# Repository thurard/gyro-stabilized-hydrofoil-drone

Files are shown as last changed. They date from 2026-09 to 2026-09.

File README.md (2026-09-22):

# 🌊 Gyro-Stabilized Hydrofoil Drone

A remote-controlled **hydrofoil drone** (a foiling boat) kept level by a
**gyroscopic stabilization system**. This SeaTech engineering project spans the whole
chain — functional analysis, **MATLAB/Simulink (Simscape) modelling**, CAD, 3D printing,
electronics and a **working prototype tested on the water**.

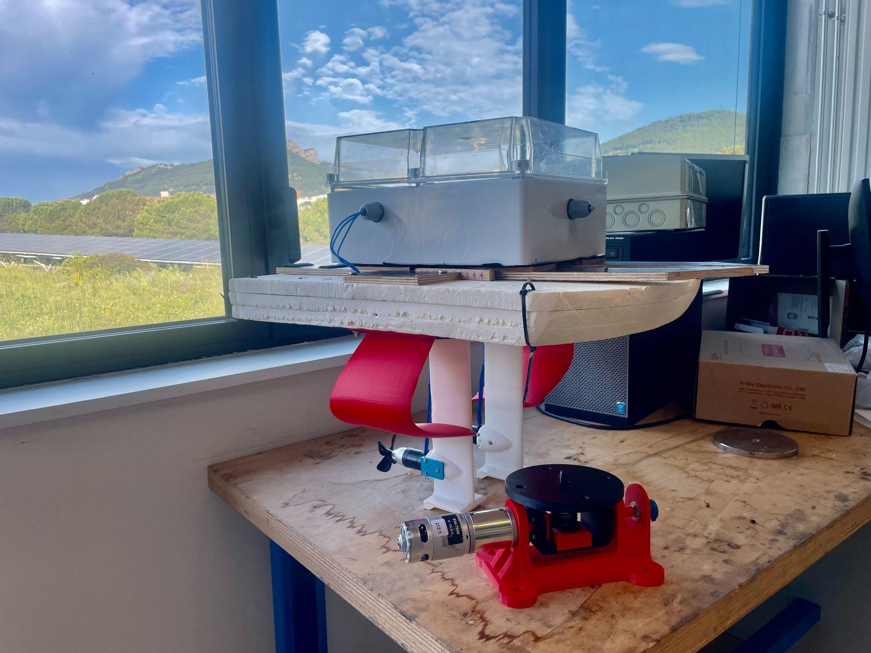
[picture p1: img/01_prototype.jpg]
Prototype


> The gyroscope in action: as the mount is tilted by hand, the spinning flywheel resists
> and holds its orientation — the same effect that keeps the foil platform level.

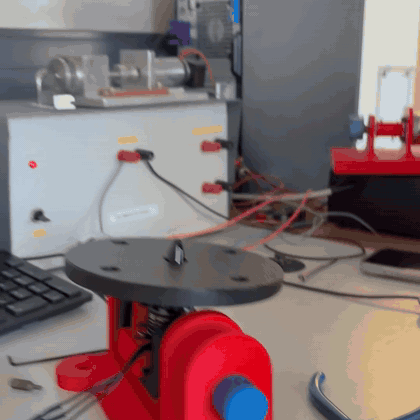
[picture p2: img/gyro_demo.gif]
Gyroscope in action


---

## Contents

- [Overview](#overview)
- [How it works](#how-it-works)
- [Simulation — the focus of this repo](#simulation--the-focus-of-this-repo)
- [Design & prototype](#design--prototype)
- [Repository structure](#repository-structure)
- [Running the simulation](#running-the-simulation)
- [Report](#-report)
- [Authors & contributions](#authors--contributions)

---

## Overview

Project of the **SYSMER** track (marine & robotic systems) at SeaTech — University of
Toulon, 2025–2026. A team of five designed and built a small remote-controlled hydrofoil
craft whose deck stays level thanks to a gyroscope.

The system combines **two complementary subsystems**:

1. **Gyroscopic stabilization** — *mechanical & passive*. A motor spins a flywheel; by
   conservation of angular momentum it resists roll and pitch and keeps the foil platform
   flat, without any active control loop.
2. **Embedded flight control** — *electronic & active*. Handles piloting, propulsion and
   the foiling height (how high the hull rides above the water).

---

## How it works

**Gyroscopic stabilization (passive).** The flywheel's angular momentum opposes any
tilt of the platform. The key design question is *where to place the centre of gravity*
so the stabilization is effective in both roll and pitch — this is exactly what the
Simulink model answers (see below).

**Embedded flight control (active).** The signal chain:

```
FlySky X7 radio → receiver → flight controller (Pixhawk / Navigator, running BlueOS)
→ Lua scripts ("motors", "height") read the height sensor and drive the motors
→ regulating the foiling height and the propulsion.
```

BlueOS is Blue Robotics' onboard operating system; the custom **Lua scripts** run on the
flight controller to close the height-regulation and propulsion loops.

---

## Simulation — the focus of this repo

The gyroscopic stabilization was modelled in **MATLAB / Simulink (Simscape Multibody)**.
The goal: find the **optimal longitudinal position of the centre of gravity** so that,
under a disturbance, the platform returns to level (0° = perfectly flat).

- `init_naca.m` — generates the **NACA 0012** foil (chord 0.15 m) and its winglet, and
  loads their coordinates into the workspace for the Simscape wing blocks.
- `Gyro_tanga.slx` + `Gyro_Tanga.m` — **pitch** study: sweeps 8 CoG positions
  (−0.25 m → −0.05 m) and plots the resulting pitch angle over time.
- `Gyro_roulis.slx` + `Gyro_Roulis.m` — **roll** study: sweeps CoG positions
  (−0.15 m → +0.15 m) and plots the roll angle.

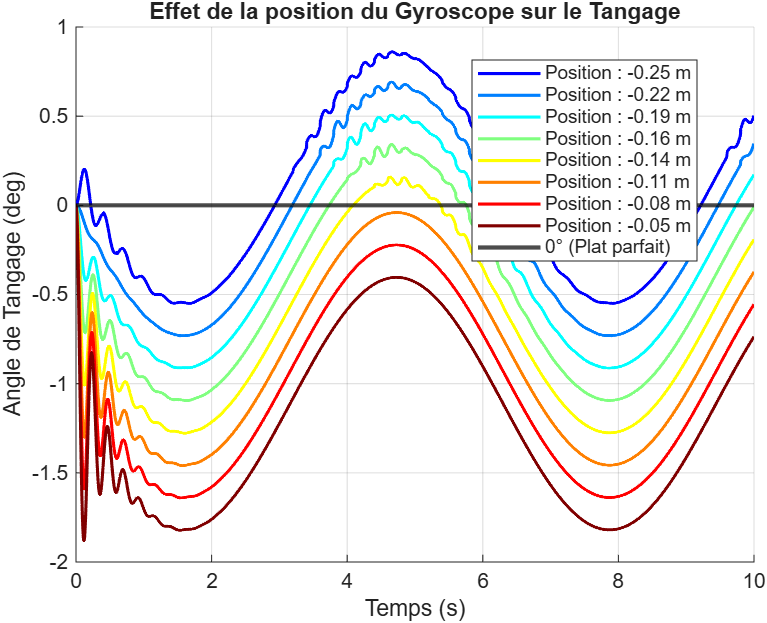
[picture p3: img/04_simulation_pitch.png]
Pitch sweep


*Effect of the CoG longitudinal position on pitch: the curve closest to 0° identifies
the best CoG placement for a stable, level platform.*

---

## Design & prototype

| | |
|---|---|
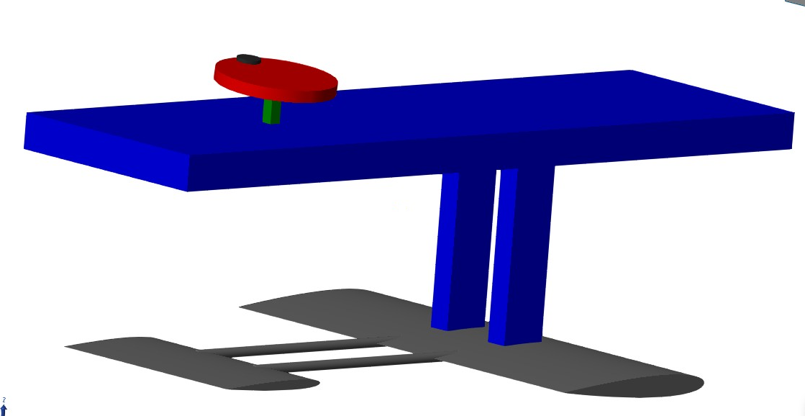
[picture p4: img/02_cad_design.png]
CAD
|  | **CAD** of the full foiling drone (deck + foils + gyroscope). |
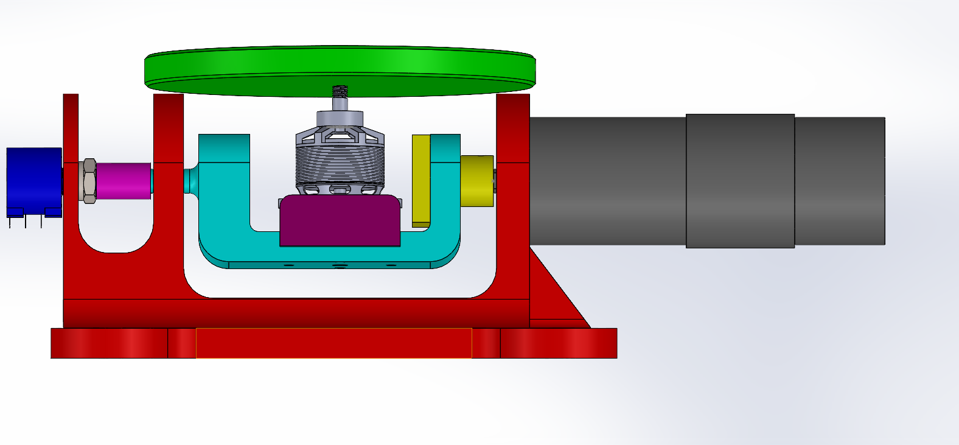
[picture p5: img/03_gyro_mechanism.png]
Gyro mechanism
|  | Cutaway of the **gyroscope mechanism** (motor + flywheel + gimbal). |
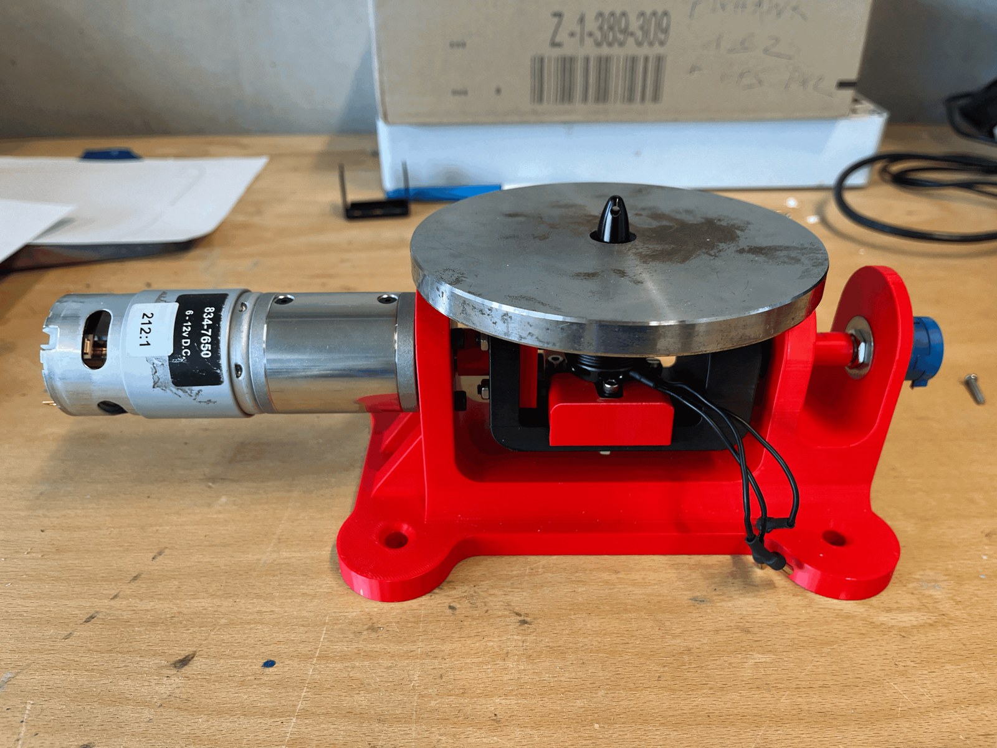
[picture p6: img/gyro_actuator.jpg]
Gyroscope prototype
|  | The **3D-printed gyroscope** assembled (mount + motor + flywheel). |
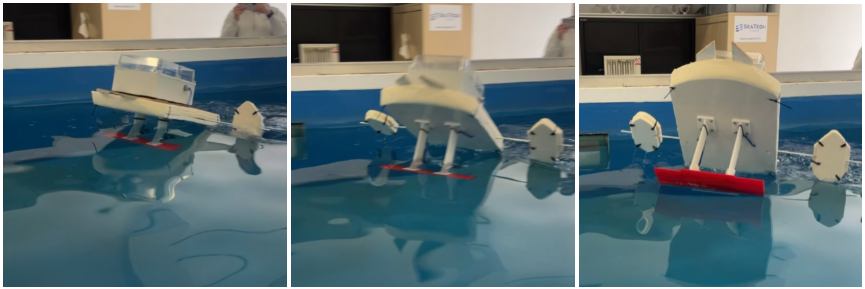
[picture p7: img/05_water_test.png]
Water test
|  | **On-water tests** of the prototype. |

The mechanical parts were **3D-printed**, assembled with the motors, flywheel, foils and
electronics, and tested on the water.

---

## Repository structure

```
.
├── init_naca.m             % NACA 0012 foil + winglet generation
├── Gyro_tanga.slx          % Simscape model — pitch
├── Gyro_Tanga.m            % CoG sweep (pitch) + plot
├── Gyro_roulis.slx         % Simscape model — roll
├── Gyro_Roulis.m           % CoG sweep (roll) + plot
├── Rapport.pdf             % Full project report (French)
├── presentation.pptx       % Project presentation (optional)
├── img/                    % Renders, prototype photos, results
└── README.md
```

---

## Running the simulation

**Requirements:** MATLAB with **Simulink** and **Simscape Multibody**.

```matlab
% From the repository folder, simply run a sweep script — it loads the NACA
% profiles and the Simulink model automatically:
Gyro_Tanga     % pitch study (sweeps the CoG, plots the pitch response)
Gyro_Roulis    % roll study
```

Each script opens its Simscape model, runs the simulation for 8 centre-of-gravity
positions, and overlays the angle responses so the best placement stands out.

---

## 📄 Report

Full project report — functional analysis, gyroscopic system, Simulink study, 3D design,
embedded system and prototype results (in French):

**➡️ [Rapport.pdf](Rapport.pdf)**

---

## Authors & contributions

Five-person project — SeaTech (University of Toulon), SYSMER, 2025–2026. Supervised by
Cédric Anthierens.

| Subsystem | Members |
|---|---|
| **Gyroscopic stabilization** (mechanical design, Simulink/Simscape modelling, CoG optimization, foil) | **Tom Hurard**, **Amélie Duchemin** |
| **Embedded flight control** (BlueOS, Lua scripting, RC piloting, height sensor, propulsion) | **Marie Bernard-Lameau**, **Anatole Collange**, **Antoine Hureau** |

*This repository centres on the gyroscopic-stabilization simulation. The embedded flight
control was developed by the other three team members and is described here for context.*

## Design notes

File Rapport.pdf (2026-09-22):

# Rapport de Projet

Réalisation d’un drone à foil télécommandé avec stabilisation gyroscopique

Encadrant :

ANTHIERENS Cédric

Étudiants :

BERNARD-LAMEAU Marie
COLLANGE Anatole
DUCHEMIN Amélie
HURARD Tom
HUREAU Antoine

SYSMER 2A

Année universitaire 2025–2026

## Table des matières

Remerciements | 3
Résumé | 4
1 Introduction | 6
2 Analyse du projet | 7
3 Système de stabilisation gyroscopique | 11

### 3.3.2 Limitation à un unique gyroscope et réorientation de l’étude . . . . 12

4 Système embarqué | 18
5 Maquette | 23

1

6 Axes d’évolution et d’amélioration du projet | 30
7 Conclusion | 32
A Coder en Lua | 33
B Tutoriel BlueOS | 37
C Scripts MATLAB | 41
D Mises en plan | 44
E Protocole d’assemblage | 51

2

## Remerciements

Nous tenons à remercier chaleureusement toutes les personnes ayant collaboré, de près ou de loin, à la réalisation de ce projet.
Tout d’abord, nous tenons à remercier M. ANTHIERENS, notre enseignant référent, de nous avoir encadrés et conseillés tout au long de notre projet, tant sur la méthodologie de travail que sur la résolution des différentes problématiques techniques rencontrées. Nous tenons aussi à remercier M. DEGORRE, pour sa réactivité et son aide précieuse concernant les montages électriques, l’utilisation de Blue OS et la conception de pièces tout au long de ce projet.
Nous remercions également les étudiants des années précédentes — Amélie VOGEL, Matthis BARRIOL, Chloé BERTRAND-ADAM, Anthony GRAILLE et Arthur VARRE, — de nous avoir guidés et d’avoir partagé leurs travaux avec nous, nous permettant ainsi de reprendre ce projet dans les meilleures conditions.

3

## Résumé

Ce projet s’inscrit dans la continuité des travaux menés par d’anciens élèves en partenariat avec l’entreprise ZYX Blue, portant sur la conception d’un drone de surface à foil télécommandé équipé d’un système de stabilisation gyroscopique. Ainsi, l’objectif est de permettre au drone de décoller sur ses foils et de maintenir son altitude, grâce à une combinaison de solutions mécaniques, hydrodynamiques et électroniques.

Un nouveau foil autostabilisant a été conçu sous SolidWorks pour pallier l’instabilité du foil en T. Le système gyroscopique a été entièrement repensé avec une architecture en U plus rigide et compacte, validée par prototypage rapide. Le système embarqué repose sur une Raspberry Pi 5 couplée à une carte Navigator, fonctionnant sous BlueOS, et commandé via une télécommande Taranis QX7 à 8 canaux. Des scripts Lua ont été développés pour la commande différentielle des moteurs de propulsion et la gestion du gyroscope. Un capteur à ultrasons a été intégré pour l’estimation de la hauteur de vol, même si la lecture des données avec la carte Navigator reste à finir. Des essais en bassin ont validé la flottabilité de la maquette (environ 10 L pour une masse totale de 4,1 kg) et permis d’obtenir des décollages répétables, même si la stabilisation automatique en altitude n’est pas encore opérationnelle.

Mots-clés

Drone foil, Stabilisation gyroscopique, BlueOS, ArduPilot, Lua, Raspberry Pi, Télécommande RC, Foil autostabilisant

4

Summary

This project builds on work previously carried out by former students in partnership with the company ZYX Blue, focusing on the design of a remote-controlled surface foil drone equipped with a gyroscopic stabilisation system. The aim is to enable the drone to take off on its foils and maintain its altitude, using a combination of mechanical, hydrodynamic and electronic solutions.

A new self-stabilising foil has been designed in SolidWorks to address the instability of the T-shaped foil. The gyroscopic system has been completely redesigned with a more rigid and compact U-shaped architecture, validated through rapid prototyping. The onboard system is based on a Raspberry Pi 5 coupled with a Navigator board, running on BlueOS, and controlled via an 8-channel Taranis QX7 remote control. Lua scripts have been developed for the differential control of the propulsion motors and the management of the gyroscope. An ultrasonic sensor has been integrated to estimate flight altitude, although data reading with the Navigator board still needs to be finalised. Tank tests have validated the model’s buoyancy (approximately 10 L for a total mass of 4.1 kg) and enabled repeatable take-offs, even though automatic altitude stabilisation is not yet operational.

Key words

Foiling drone, Gyroscopic stabilization, BlueOS, ArduPilot, Lua, Raspberry Pi, RC remote control, Self-stabilising foil

5

## 1 Introduction

Le développement d’un drone foileur performant représente un enjeu majeur pour la robotique marine moderne. Les foils permettent d’atteindre des vitesses élevées tout en réduisant la traînée, mais ils introduisent en contrepartie une forte sensibilité aux perturbations et aux variations d’assiette. La stabilité devient alors un facteur critique : sans un contrôle précis et réactif, le drone perd en efficacité, en sécurité et en capacité opérationnelle. C’est précisément pour répondre à cette problématique que ce projet s’inscrit dans la continuité des travaux menés au COSMER et avec l’entreprise ZYX Blue sur l’équilibrage dynamique par effet gyroscopique.
Ce projet reprend les travaux entrepris lors de précédents projets 2A et 3A SYSMER. Les promotions précédentes ont posé des bases importantes : une première architecture gyroscopique, un foil en T fonctionnel, et une maquette. Mais le travail n’était pas fini. Aucune implémentation n’avait été réalisée sous BlueOS, l’électronique était à revoir, le foil en T présente une tendance au phénomène de décrochage difficile à maîtriser et le gyroscope n’avait jamais été activé en conditions réelles.
Notre travail s’est donc organisé autour de trois axes principaux. D’abord, mettre en place l’ensemble du système embarqué sous BlueOS (commande moteur, télécommande, capteur de hauteur). Ensuite, repenser l’architecture mécanique du gyroscope pour la rendre plus compacte. Enfin, concevoir un nouveau foil à géométrie autoadaptative pour répondre au problème de décrochage constaté en bassin.

6

## 2 Analyse du projet

### 2.1 Cahier des charges et attendus du projet

Le projet consiste à concevoir un drone de surface à foils télécommandé, doté d’un système de stabilisation gyroscopique. Pour ce faire, nous avons réalisé les tâches suivantes :
— Intégration d’une télécommande et de son récepteur pour piloter les moteurs de propulsion par liaison radio,
— Réalisation de tests en bassin pour valider la flottabilité, l’étanchéité, et l’efficacité des foils,
— Dimensionnement et conception du système de stabilisation gyroscopique,
— Intégration d’un capteur de distance à ultrasons pour connaître la hauteur de vol pour garantir la stabilité du drone,
— Commande des gyroscopes, si l’intégration matérielle et logicielle le permet.
Une maquette composée d’un flotteur en mousse et d’un foil en T a déjà été réalisée par les groupes précédents.
Pour réaliser le système embarqué, nous disposons de :
— une boîte de dérivation étanche et des presse-étoupe,
— 1 Raspberry Pi couplée à une carte Navigator,
— 4 ESC, dont 3 brushless,
— 2 batteries,
— 1 télécommande et le récepteur associé,
— 1 buck converter,
— 4 moteurs : 2 pour la propulsion, 2 pour piloter le gyroscope. Pour réaliser le système gyroscopique, nous disposons de :
— 1 moteur brushless outrunner (600KV T-HOBBY)
— 1 motoreducteur à courant continu (834-7650 RS PRO)
— 1 potentiomètre 10 tours (2780303 RS PRO)
— 1 disque en métal de 1 kg

### 2.2 Analyse fonctionnelle

L’analyse fonctionnelle du drone vise à formaliser les interactions entre le système et son environnement extérieur, ainsi qu’à traduire les besoins exprimés en fonctions techniques. Cette étape préalable a guidé les choix d’architecture, en particulier pour la stabilisation gyroscopique, la propulsion, l’étanchéité et l’interface de pilotage.

7

### 2.2.1 Interacteurs

Il existe quatre entités extérieures en interaction avec le système. L’utilisateur pilote le drone, reçoit des informations sur sa position par rapport aux obstacles, et assure le transport ainsi que la mise à l’eau. La charge à déplacer sur l’eau constitue la prestation principale attendue du drone. L’environnement regroupe l’eau, le vent, les obstacles immergés ou en surface, ainsi que les agents de corrosion. Enfin, les ondes radio et l’alimentation électrique embarquée sont des interacteurs nécessaires au fonctionnement.

### 2.2.2 Fonctions de service

Deux fonctions de service (FP) ont été identifiées. La première (FP1) consiste à permettre à l’utilisateur de déplacer une charge sur l’eau. Les critères d’appréciation sont la vitesse de déplacement (au moins 2 nœuds), la capacité de charge utile (supérieure à 0,5 kg) et la stabilité de l’assiette en vol sur foils (maintien à ±10°). La seconde fonction (FP2) est d’informer l’utilisateur en temps réel de la position du drone par rapport aux obstacles environnants. Elle est assurée par un capteur à ultrasons qui mesure la hauteur de vol ou la distance aux obstacles, avec une portée minimale de 2 m et une fréquence de mise à jour d’au moins 10 Hz.

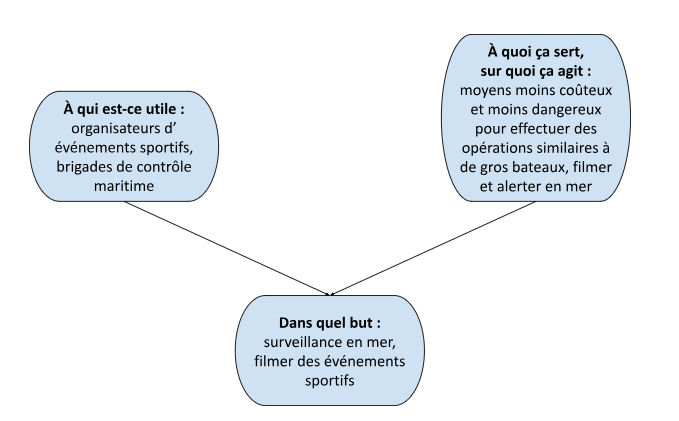
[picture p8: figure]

Figure 2.1 – Bête à cornes du système

### 2.2.3 Fonctions de contrainte

Quatre fonctions de contrainte (FC) ont été identifiées. FC1 impose de résister aux perturbations du vent tout en maintenant la transmission des ondes radio. La stabilité active est obtenue par un effet gyroscopique agissant prioritairement sur l’axe de tangage, tandis

8

que la liaison radio doit rester fiable jusqu’à 50 m. FC2 exige une résistance à la corrosion, une étanchéité du boîtier électronique aux éclaboussures, ainsi qu’une génération de portance par les foils. L’indice de protection visé est au minimum IP65 . FC3 vise une consommation électrique minimale afin de maximiser la durée de vol sur foils. Cela se traduit par une optimisation de la masse embarquée, un rendement élevé des moteurs brushless et une gestion de puissance par bridage (33%, 67%, 100%). Enfin, FC4 impose que le drone soit facile à transporter (masse totale < 6 kg), simple à mettre à l’eau (assemblage par velcro) et doté d’une interface de pilotage intuitive (télécommande Taranis QX7 avec mixage gaz/direction).

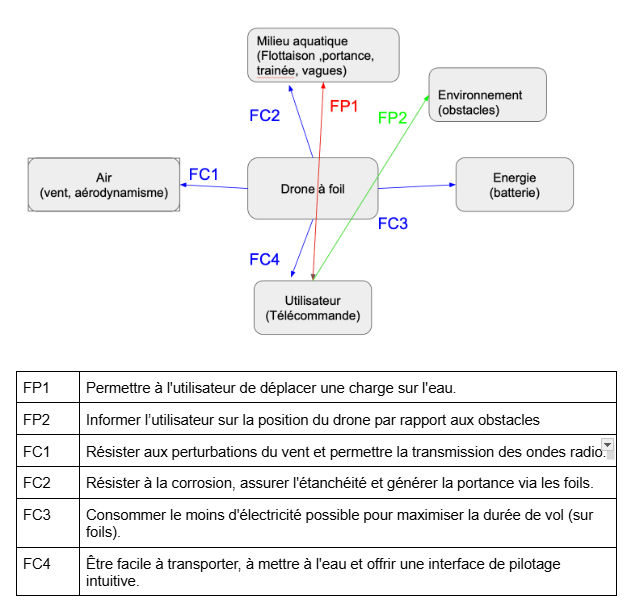
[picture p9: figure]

Figure 2.2 – Diagramme pieuvre du système

### 2.2.4 Allocation des fonctions aux sous-systèmes

Les fonctions précédentes sont réparties entre plusieurs composants techniques. La planche porteuse assure la flottabilité, le support des éléments et l’accueil de stabilisateurs latéraux amovibles. Le système gyroscopique réalise la stabilisation active en tangage (axe réorienté

9

après essais). La propulsion met en œuvre deux moteurs brushless associés à leurs ESC et à des hélices. Le système embarqué exécute des scripts Lua pour la commande moteur et la gestion du gyroscope. La télécommande et son récepteur 8 canaux fournissent l’interface homme-machine via des signaux PWM. Un capteur de hauteur à ultrasons est destiné à l’estimation de l’altitude de vol pour une régulation automatique. Enfin, le foil génère la portance hydrodynamique nécessaire au décollage.

10

## 3 Système de stabilisation gyroscopique

### 3.1 Présentation

La conception de notre système de stabilisation s’inscrit dans la continuité des travaux menés par A. Vogel, M. Barriol et C. Bertrand-Adam. Dans leur rapport, après avoir écarté l’idée de deux inerties en rotation de sens contraire, ils avaient abouti à une architecture basée sur un montage en colonne. Leur solution s’appuyait sur l’utilisation de deux gyroscopes distincts pour contrôler indépendamment les degrés de liberté, avec un servomoteur positionné en partie basse et une fixation réalisée par pliage. Bien que cette base ait permis de valider les concepts théoriques d’actionnement, nos propres contraintes d’intégration et le besoin d’optimisation (résistance des matériaux aux contraintes du disque et encombrement dans la boîte de dérivation) nous ont poussés à repenser la structure. C’est dans cette optique que nous avons apporté plusieurs améliorations et totalement redessiné l’architecture du support du gyroscope, dont la nouvelle configuration sera détaillée dans les sections suivantes.

### 3.2 Analyse cinématique et degrés de liberté

L’analyse des six degrés de liberté est fondamentale pour assurer la stabilité du drone à foil en coordonnant l’ensemble des composants électroniques et mécaniques à notre disposition. Le contrôle des rotations de roulis et de tangage repose sur le système gyroscopique constitué d’un disque mis en rotation par un moteur brushless et orienté par un motoréducteur à courant continu piloté en position. L’inclinaison contrôlée de cet ensemble permet d’appliquer des efforts correctifs directs sur la planche pour stabiliser son assiette face aux perturbations.
Le maintien de la hauteur de vol, correspondant au degré de liberté vertical (pilonnement), sera assuré par le capteur à ultrasons étanche SEN0311 qui transmettra la distance à la surface de l’eau pour ajuster dynamiquement la vitesse de rotation des deux moteurs de propulsions. Enfin, le lacet est géré par la poussée différentielle de ces mêmes propulseurs, permettant de diriger le drone et de maintenir son cap sans nécessiter de gouvernail mécanique.
L’ensemble de ces interactions est orchestré par la carte Dynamixel OpenRB-150, qui centralise la gestion des actionneurs et le traitement des mesures pour maintenir l’équilibre global du système en navigation.

11

### 3.3 Simulation Matlab Simulink

### 3.3.1 Modèle optimal

Dans les rapports précédents, il a été prouvé que pour une stabilisation optimale et équilibrée il était nécessaire de se munir de deux systèmes gyroscopiques. En effet, l’un sera en charge de la stabilisation en tangage, suivant l’axe Y et l’autre en roulis, suivant l’axe X.
Grâce à la simulation établie par le groupe de projet de la promotion 2025, nous avons pu l’adapter à notre étude et ajouter des éléments qui nous semblaient intéressants.

### 3.3.2 Limitation à un unique gyroscope et réorientation de l’étude

L’architecture initiale du projet reposait sur l’intégration de deux systèmes gyroscopiques distincts afin de dissocier le contrôle des axes de roulis et de tangage. Néanmoins, lors de la phase de conception matérielle, les contraintes d’encombrement au sein du boîtier électronique étanche ont rendu impossible l’intégration simultanée des deux actionneurs. Par conséquent, l’étude s’est adaptée pour se concentrer sur l’implémentation d’un unique gyroscope.
Cette contrainte matérielle offre toutefois une flexibilité mécanique : une fois le système opérationnel, le module gyroscopique pourra être physiquement orienté pour travailler indépendamment sur l’axe de roulis ou de tangage.
Ce choix d’axe a fait l’objet d’une réévaluation stratégique. L’étude préliminaire ciblait principalement la stabilisation en roulis, dans l’optique de faciliter les virages et la maniabilité du foil. Cependant, l’analyse des récents essais pratiques a mis en évidence une problématique de vol beaucoup plus critique : le foil présentait une difficulté majeure à maintenir son assiette longitudinale suivant sa position horizontale. Face à cette instabilité critique pour le maintien en vol, la décision a été prise de réorienter intégralement l’étude du gyroscope vers la compensation en tangage.
La boîte de dérivations avait initialement été installée pour faciliter l’organisation des composants à l’intérieur, cependant le système gyroscopique imposait une installation longitudinale. L’intégration finale nécessitera une rotation à 90° de la boîte de dérivation afin d’aligner l’axe de l’actionneur gyroscopique avec l’axe de tangage du drone.

L’enjeu des simulations suivantes est donc d’analyser le comportement dynamique de la planche face à la houle, afin de valider quel axe nécessite prioritairement la puissance instantanée avec le couple de redressement du gyroscope embarqué.

### 3.3.3 Fidélisation du modèle numérique

Afin de garantir la validité des résultats, une phase de mise en conformité du modèle Simulink hérité des travaux précédents a été nécessaire. L’objectif était de rendre le modèle numérique le plus fidèle possible au prototype physique actuel. Les modifications suivantes ont été apportées : -Géométrie : Ajout d’un second mât et intégration des profils hydro-

12

dynamiques NACA.
- Appendices : Modélisation d’une ailette stabilisatrice pour refléter la traînée et la portance réelles.

### 3.3.4 Protocole de recherche du centre de gravité par balayage

Une fois le modèle stabilisé, un script MATLAB a été développé pour identifier "expérimentalement" le centre de gravité optimal du système. Ce protocole repose sur une méthode de balayage : Le code fait varier automatiquement la position longitudinale du bloc gyroscopique sur toute la longueur du foil.
Pour chaque itération, le script enregistre les signaux de position angulaire (axes X et Y) ainsi que la capacité du système à absorber les perturbations de la houle.

L’enjeu est de trouver le point d’équilibre passif où le gyroscope n’a pas à compenser le poids propre du drone, évitant ainsi la saturation mécanique du moteur (maintien dans la plage des 30°).

### 3.3.5 Analyse des résultats et arbitrage technique

L’étude comparative des deux axes a révélé des comportements physiques distincts :
- En tangage (Axe Y) : Les résultats montrent que la position du gyroscope agit linéairement sur la réactivité du foil. Un décalage, même mineur, entraînerait une erreur statique permanente (nez plongé ou cabré), rendant le maintien d’une assiette horizontale impossible sans correction active.
- En roulis (Axe X) : À l’inverse, la position longitudinale du bloc n’influence que très marginalement la stabilité latérale. Les variations observées ne justifient pas une étude de positionnement approfondie sur cet axe.

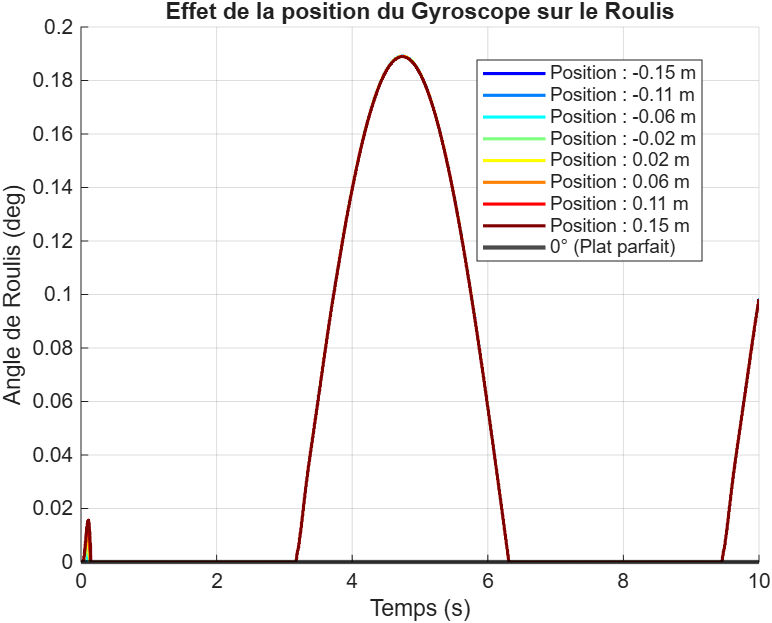
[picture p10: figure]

Figure 3.1 – Simulation Tangage | Figure 3.2 – Simulation Roulis

En conclusion, la simulation valide notre choix stratégique : l’étude en tangage est prioritaire. Cette configuration facilite également les futures expérimentations en bassin, car

13 elle permet d’ajuster plus simplement la position du gyroscope pour compenser les modifications fréquentes apportées au centre de gravité du prototype réel.

### 3.4 Conception 3D

### 3.4.1 Nouvelle architecture

Nous avons adapté l’architecture du gyroscope et de son support pour optimiser l’espace occupé dans le caisson étanche, mais également pour gagner en fiabilité et en solidité grâce à une structure en U, qui remplace l’ancien assemblage en colonne. Ce support en U, qui transmet les efforts de compensation au drone, offre une meilleure rigidité structurelle et sera en mesure d’encaisser des contraintes mécaniques plus importantes sur la durée. Par conséquent, le moteur de précession en charge de l’inclinaison du volant d’inertie a été remplacé afin d’être parfaitement dimensionné pour cette nouvelle cinématique et compenser efficacement les mouvements du drone avec cette nouvelle architecture.

L’ensemble de cette structure a pu être validé par prototypage rapide en impression 3D. Dans cette logique de modularité, nous avons également conçu le disque d’inertie en plastique. Cette approche nous permet de faire varier facilement la masse embarquée et d’ajuster le moment d’inertie en y insérant des écrous de différentes tailles selon les besoins des essais.

Enfin, le moyeu d’accouplement reliant le moteur de précession au système est actuellement imprimé en plastique afin de valider l’assemblage global. À terme, cette pièce d’interface doit être usinée en aluminium pour garantir une solidité maximale et une transmission d’effort optimale lors des tests en conditions réelles. La mise en plan à envoyer pour usinage est en annexe.

### 3.4.2 Ajustement structurel et gestion des interfaces mécaniques

Lors de la phase d’assemblage final, un défaut de dimensionnement concernant l’encombrement du motoréducteur a été identifié. En raison d’un décalage entre les cotes théoriques du moteur et l’espace disponible, le disque du gyroscope entrait en contact avec la partie supérieure du socle, empêchant ainsi sa libre rotation.
Pour pallier ce problème sans compromettre l’intégrité du système, une modification de la conception du socle a été effectuée. Nous avons intégré une cale de rehausse directement sur le support en U. Cette pièce intermédiaire permet d’élever l’axe du disque, garantissant un jeu fonctionnel suffisant pour une rotation sans frottement.
Cette itération a également été mise à profit pour optimiser les points de fixation du motoréducteur, assurant ainsi une meilleure rigidité de l’ensemble moteur-disque lors des phases de précession rapide.

14

### 3.4.3 Gamme de montage

Pour garantir la compatibilité des composants et optimiser le processus de construction, nous avons établi une gamme de montage structurée (en annexe). Cette démarche permet de définir précisément l’ordre d’assemblage et de valider l’ajustement des pièces.
Le montage est séparé en plusieurs blocs, dont la composition dépend de la position des pièces et de leurs fonctions mécaniques. Alors que le support en U du gyroscope et le socle rouge constituent les structures de base, les composants mobiles sont regroupés comme suit :
- Le bloc potentiomètre : dédié au retour d’information angulaire.
- Le groupe motoréducteur : responsable de l’orientation du système.
- Le groupe moteur : ensemble principal assurant la rotation du disque.

Cette phase de planification a permis de recenser précisément les besoins en fixations. Le montage s’appuie sur une sélection de vis et de boulons dont les diamètres s’échelonnent de 3 mm à 6 mm, avec des références standardisées telles que les vis M2x8 et M3x8. Concernant la fabrication, le choix des matériaux est dicté par les contraintes mécaniques de la fabrication additive et des efforts intenses. D’abord, la fabrication additive est privilégiée pour les pièces structurelles complexes afin d’optimiser le poids total. Ensuite, l’aluminium est utilisé pour les éléments subissant les efforts les plus intenses. À ce titre, la pièce assurant la liaison entre le motoréducteur et le support en U doit impérativement être réalisée en aluminium pour garantir la fiabilité de la transmission.

Les mises en plan de toutes les pièces fondamentales sont en annexe.

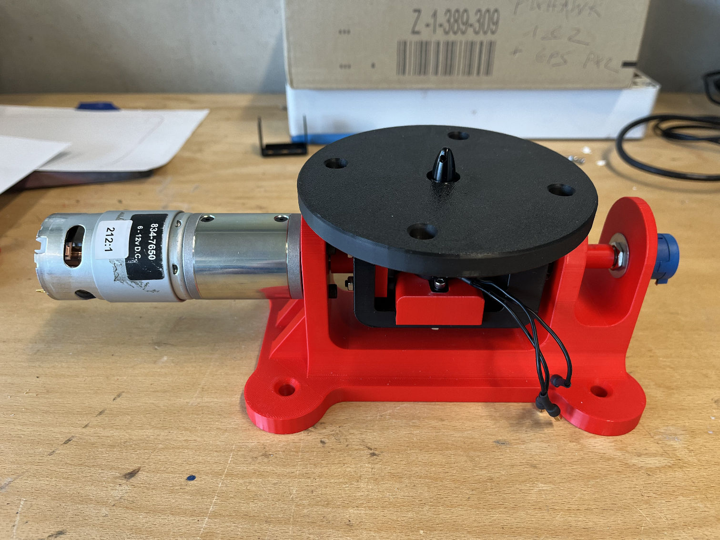
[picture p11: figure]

Figure 3.3 – Assemblage du système gyroscopique avec disque en fabrication additive

15

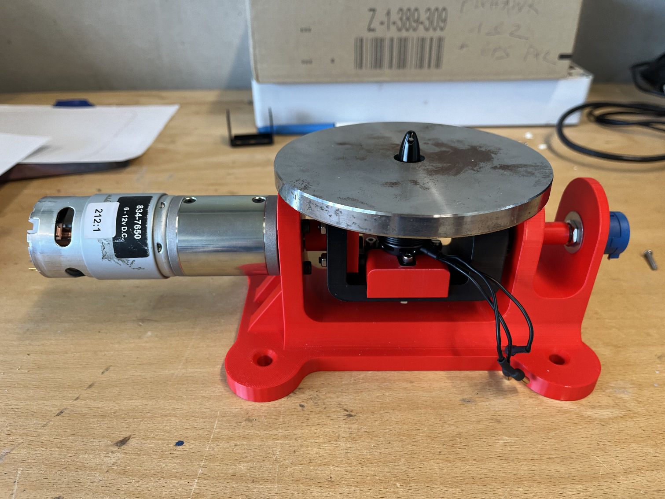
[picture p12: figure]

Figure 3.4 – Assemblage du système gyroscopique avec disque en métal (1 kg)

### 3.5 Choix des composants

A l’aide des groupes précédents, nous avons pu réutiliser les moteurs qui avaient été sélectionnés.

En ce qui concerne la motorisation du système gyroscopique, le choix s’est porté sur des moteurs brushless outrunner, spécifiquement le modèle AS2308 2600KV de chez T-HOBBY. Cette technologie à rotor externe a été privilégiée pour son rendement énergétique et sa densité de puissance, offrant des performances mécaniques supérieures aux moteurs inrunners pour un encombrement équivalent. Bien que les besoins du projet n’imposent pas de couple de démarrage excessif, ce moteur de 275 W assure une réserve de puissance optimale pour entraîner la masse d’inertie voulue, allant jusqu’à 1 kg . Le diamètre d’axe de 4 mm garantit par ailleurs une rigidité de liaison suffisante pour supporter les variations de masse lors des phases de test, tout en restant dans des plages de vitesse de rotation sécuritaires pour le système.

Le contrôle de l’assiette du drone est assuré par un motoréducteur à courant continu de la gamme RS PRO, fonctionnant sous une tension nominale de 12 V. Ce moteur à balais développe une puissance de 41,3 W et a été spécifiquement sélectionné pour sa capacité à délivrer un couple de blocage de 2,5 N.m avec une vitesse de sortie de 33 tr/min (ajustée à 27 tr/min selon les configurations de réduction). Ce choix technologique répond à la nécessité d’obtenir un mouvement angulaire lent et précis, indispensable pour compenser les perturbations hydrodynamiques et maintenir la stabilité du vol sur foil. L’intégration mécanique de cet actionneur repose sur un arbre de sortie d’un diamètre de

16

### 8 mm, garantissant une transmission robuste du couple vers l’axe principal du système gy-

roscopique. Ce dimensionnement permet de respecter les contraintes de flexion de l’arbre et d’assurer un alignement rigoureux au sein de l’équerre de fixation en U. En supportant une intensité maximale de 5,5 A, ce motoréducteur offre la réserve de couple nécessaire pour absorber les efforts induits par les variations d’inclinaison, validant ainsi les calculs dynamiques préalablement effectués sous l’environnement Matlab Simulink.

Afin d’assurer un asservissement précis de l’inclinaison du disque d’inertie, le système intègre un potentiomètre de précision RS PRO de la série 3590. Ce modèle multi-tours (10 tours) est particulièrement adapté aux exigences de résolution du projet, car il permet de traduire le mouvement angulaire de précession en un signal analogique d’une grande finesse. Cette résolution accrue est indispensable pour obtenir une lecture fidèle de l’assiette en temps réel, permettant au contrôleur de détecter des variations d’angles infimes que des potentiomètres mono-tour standards ne pourraient capturer avec la même linéarité.

17

## 4 Système embarqué

### 4.1 Hardware

Figure 4.1 – Schéma électrique du drone

L’ensemble des composants utilisés pour le contrôle du drone et leur agencement est présenté dans le schéma ci-dessus. Une seule et même batterie 3S alimente l’ensemble du système.
L’utilisation de 3 ESC permet l’alimentation et la commande des deux moteurs de propulsion et du moteur qui met en rotation le disque du gyroscope. Un quatrième ESC est présent dans le schéma et est destiné à alimenter le moteur qui incline le module gyroscopique. Nous n’avons pas pu alimenter ce moteur car l’ESC disponible (DRI0002 2A Dual Motor Controller) n’est pas adapté pour ce type de moteur étant donné que l’intensité requise du moteur est deux fois plus élevée que celle fournie par l’ESC (5,5A nécessaire contre 2A disponibles).
Le branchement se fait via trois câbles. Après le branchement des propulseurs, il faut s’assurer que les hélices des moteurs tournent dans le bon sens, si ce n’est pas le cas il

18 suffit d’inverser deux fils.
La carte que nous utilisons est une Navigator couplée à une Raspberry Pi5 (présente cidessous). Notre carte est alimentée par une tension constante de 5V environ, fournie par la batterie et stabilisée par le buck converter qui empêche ainsi d’endommager la carte à cause d’un saut de tension.
Pour pouvoir commander notre drone nous utilisons une Radio Télécommande Taranis Q X7 qui communique avec le recepteur branché sur notre Navigator sur le port RC. Enfin on utilise un capteur ultrason branché sur un port Serial destiné à estimer la hauteur du drone par rapport à la surface de l’eau.

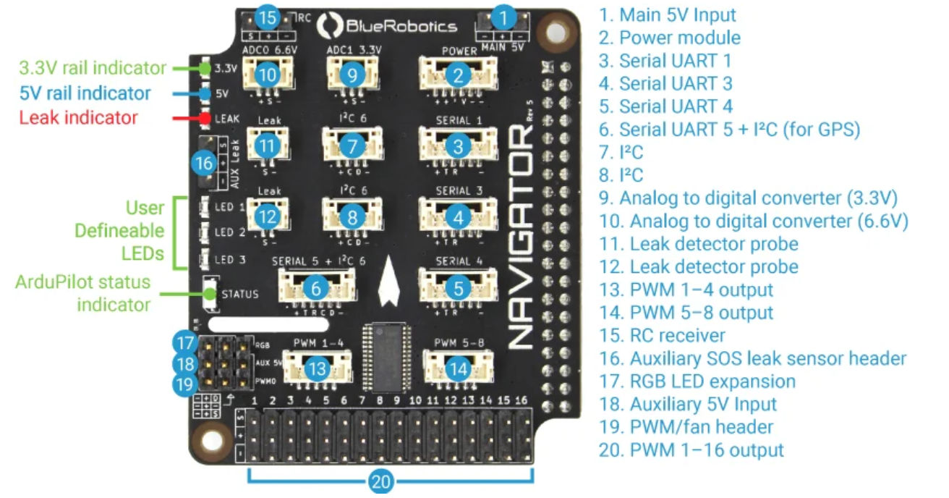
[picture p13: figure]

Figure 4.2 – Schema Carte Navigator

### 4.2 Software

Nous avons utilisé le software Blue OS de Blue Robotics. L’interface se fait grâce à un interface logiciel web accessible à l’adresse 192.168.2.2

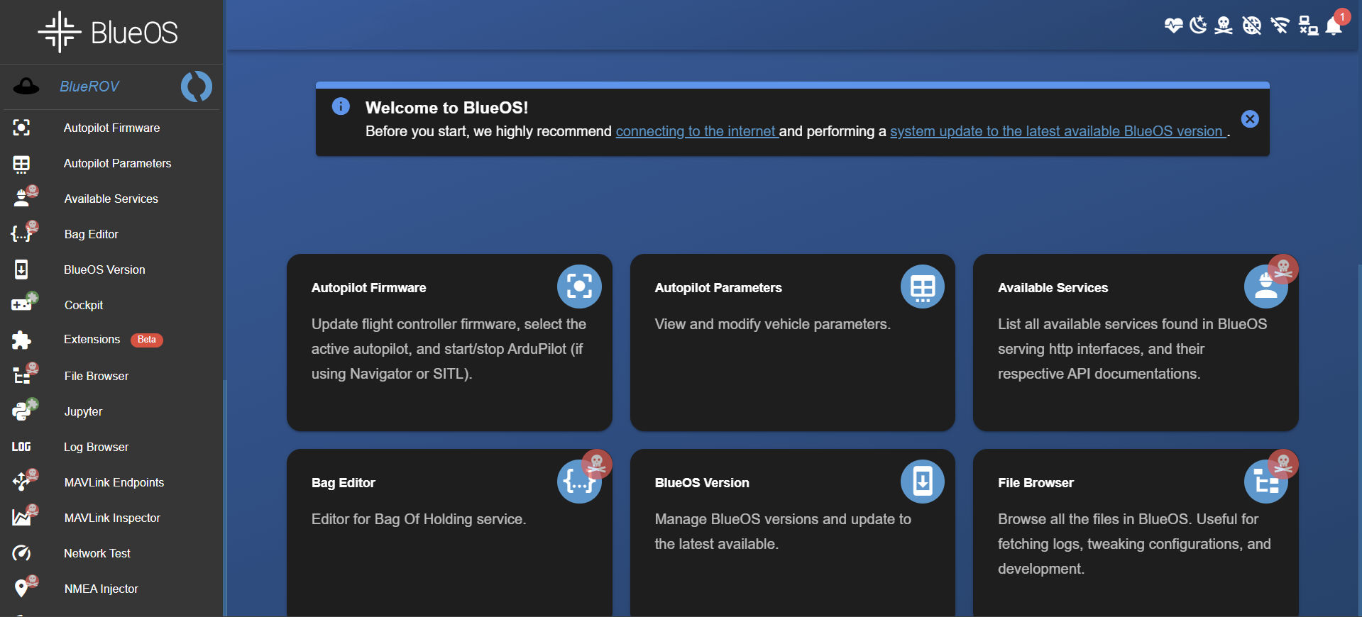
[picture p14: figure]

Figure 4.3 – Blue OS

Un tutoriel d’utilisation est disponible en (B)

19

Ce logiciel gère toutes les caractéristiques du robot.
Nous avons le moyen de coder en lua sur Blue OS. Ainsi nous pouvons imaginer des codes pour pouvoir piloter comme on le souhaite le robots avec la radio-télécommande.

Nous avons donc fait un premier code en lua (A.1). Ce code permet de contrôler les deux moteurs. On utilise un des joystick pour la puissance, un autre pour mettre un différentiel de puissance entre les deux moteurs (afin de tourner). On utilise un des bouton de la télécommande pour brider la puissance à (33%, 67%, ou 100%). Enfin un autre bouton pour désactiver les moteur.

### 4.3 Télécommande

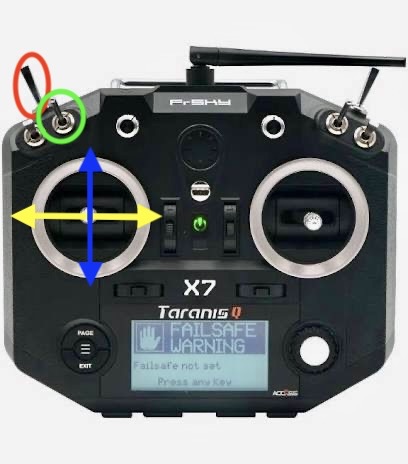
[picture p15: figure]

Figure 4.4 – RC Taranis X Q7

Notre RC Taranis QX7 avec récepteur possède 8 canaux de communication. Nous avons opté pour une ergonomie intuitive afin de simplifier la conduite du drone, notamment

20 lors des phases critiques de décollage du foil. L’axe vertical du joystick gauche contrôle la vitesse de rotation des moteurs (en bleu) et le différentiel entre les propulseurs est contrôlé par l’axe horizontal (en jaune). L’interrupteur en rouge permet d’armer ou de désarmer les moteurs. Enfin l’interrupteur vert possède trois positions pour la puissance des moteurs : bridé à 33% , 66% ou 100% de la vitesse max.
Pour établir pour la première fois la connexion entre le récepteur et la Radio-Télécommande il faut suivre un protocole assez long détaillé sur la notice du fournisseur facilement trouvable sur internet. Ce protocole garantit qu’aucun autre émetteur ne peut prendre le contrôle du drone.
Pour les séquences d’initialisation suivantes, une routine de sécurité est nécessaire. Après l’allumage de la radio et de la Navigator, le système ArduPilot effectue des "Pre-arm checks". Parfois, une remise au neutre des joysticks ou un cycle d’alimentation est requis pour valider que tous les capteurs (dont notre capteur de distance) et les sécurités sont opérationnels avant de permettre l’armement via l’interrupteur rouge.

21

### 4.4 Capteur de vol

Concernant le câblage et la connexion à la carte Navigator, la liaison série nécessite que le fil de transmission du capteur (fil jaune) soit raccordé à la borne de réception (RX) du port Serial de la Navigator, et inversement pour le fil blanc. Une vérification à l’oscilloscope a confirmé que le capteur émet un signal cohérent, variant proportionnellement à la distance de l’obstacle ; le défaut de lecture identifié est donc d’ordre strictement logiciel. En effet, BlueOS n’interprétant pas nativement le protocole de données envoyé, les résultats affichés initialement étaient incohérents. Une fois cette communication stabilisée, le capteur deviendra la pièce maîtresse de la régulation verticale du drone. Si les premiers essais, réalisés avec le foil d’origine et le modèle « à moustache », ont validé la facilité de décollage, ils ont également souligné la difficulté de maintenir une altitude de vol constante sans assistance. L’exploitation des données de hauteur, couplée à un algorithme de lissage de l’accélération (A.2), permettra d’asservir le drone à une hauteur cible précise, garantissant ainsi la stabilité et la pérennité du vol sur foil.

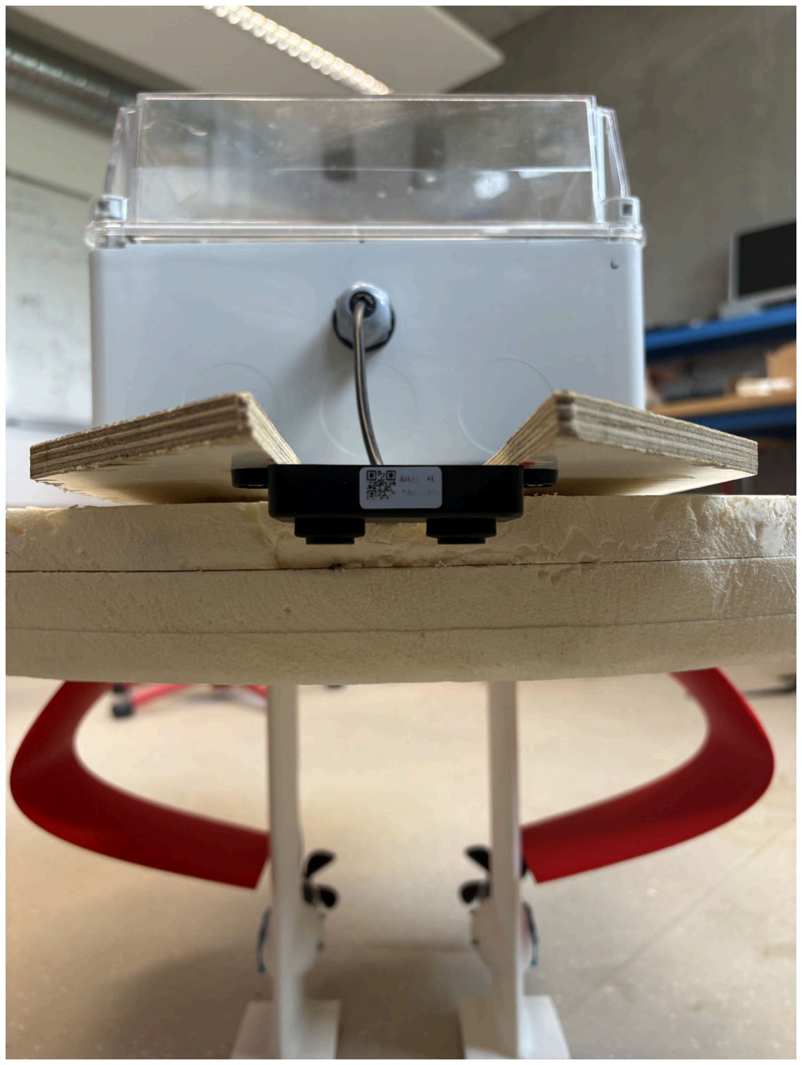
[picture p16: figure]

Figure 4.5 – Capteur de hauteur modèle A0221AU

22

## 5 Maquette

### 5.1 Dimensionnement de la planche

Le flotteur initial était constitué d’une planche de mousse de dimensions 40×60×2 cm, découpée en pointe à l’avant. Nous avons retenu cette géométrie comme base de conception, tout en cherchant à l’améliorer afin de :
— garantir une flottabilité suffisante pour supporter la masse totale du drone ;
— optimiser les conditions de décollage.
En intégrant l’ensemble des composants embarqués (électronique, boîte de dérivation, gyroscopes, moteurs et batterie), la masse totale du système atteint environ 5 kg. Pour assurer la flottabilité minimale, le flotteur doit donc présenter un volume supérieur à 5 L, conformément au principe d’Archimède.
Afin d’améliorer les performances hydrodynamiques lors de la phase de décollage, nous nous sommes inspirés des flotteurs de wingfoil, caractérisés par une proue arrondie et un relèvement du profil inférieur à l’avant.

Figure 5.1 – Inspiration : planche de wingfoil

La planche finale a été obtenue par superposition de trois couches de mousse, portant l’épaisseur totale à 5,7 cm pour des dimensions finales de 40 × 57 × 5,7 cm. Le volume résultant est d’environ 10 L, ce qui garantit que la boîte de dérivation reste hors de l’eau et offre une marge suffisante pour d’éventuelles évolutions du système.
Après l’assemblage des trois couches, la partie avant a été poncée afin d’obtenir un ar-

23 rondi progressif et un relèvement du nez, améliorant ainsi la pénétration dans l’eau et la transition vers le vol.
Le flotteur final est présenté en Fig.5.2.

Figure 5.2 – Flotteur réalisé

### 5.2 Stabilisateurs

Comme la stabilité du foil était inconnue — aucun essai préalable n’ayant été réalisé — nous avons ajouté des stabilisateurs latéraux. Leur fonction est d’empêcher le retournement complet du drone, de manière à maintenir la boîte de dérivation ainsi que les composants électroniques hors de l’eau.
Les stabilisateurs ont été fabriqués dans la même mousse que le flotteur principal et présentent chacun un volume d’environ 1 L. Ils ont été fixés à l’arrière du flotteur au moyen de tiges rigides et de bandes de velcro, assurant un maintien suffisant tout en permettant un démontage rapide. La fixation permet qu’ils ne touchent pas l’eau en situation stable, mais interviennent seulement lors de forte gite.

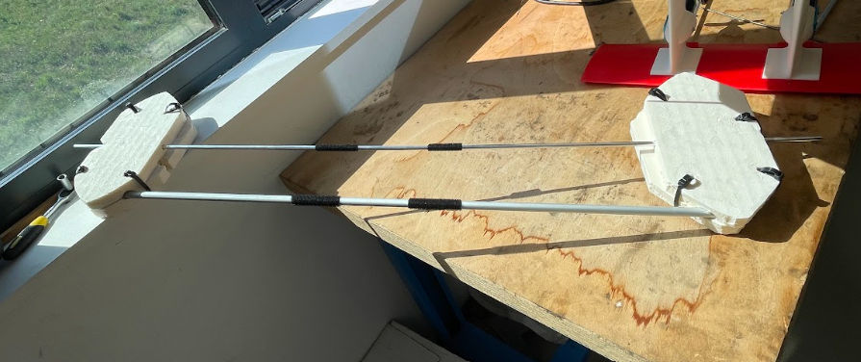
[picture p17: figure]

Figure 5.3 – Stabilisateurs latéraux

24

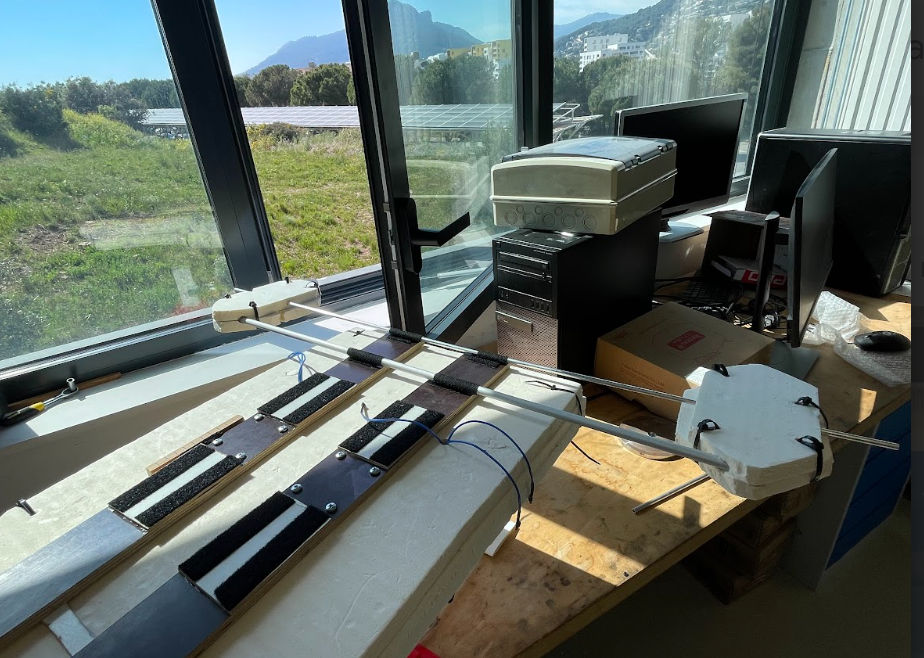
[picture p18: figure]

Figure 5.4 – Montage des stabilisateurs latéraux

### 5.3 Boîte de dérivation

Le boîtier étanche intègre l’ensemble des composants électroniques sensibles. L’étanchéité est assurée par des presses-étoupes permettant le passage des câbles d’alimentation des moteurs de propulsion ainsi que des câbles des capteurs de vol.

Les différents composants internes sont fixés à l’aide de bandes de velcro afin d’éviter tout déplacement lors des essais, limitant ainsi les risques de dégradation mécanique ou électrique. Ce mode de fixation présente également l’avantage de permettre un repositionnement rapide des composants en fonction des besoins et de la répartition des masses souhaitée.
Enfin, le boîtier peut être déplacé le long de la planche grâce à un système de velcro externe, offrant la possibilité d’ajuster la position du centre de gravité du drone en fonction des configurations de test.

25

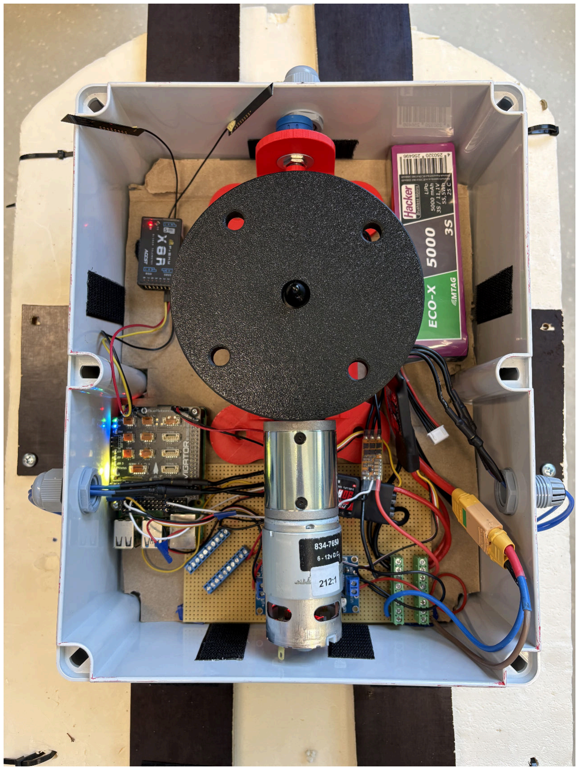
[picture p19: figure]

Figure 5.5 – Aménagement de la boîte de dérivation

Nous avons finalement réussi à placer dans la boîte l’intégralité des composants nécessaires à la navigation du drone ainsi que le premier module gyroscopique. Le module gyroscopique peut être tourné de 180 degrés pour modifier la répartition du poids dans la boîte étant donné que le moteur d’inclinaison est ici l’élément le plus lourd.

### 5.4 Foil

Lors des essais en bassin, nous avons constaté que la hauteur de vol du foil en T conçu par Anthony GRAILLE et Arthur VARRE était difficile à stabiliser. Lorsque la vitesse de rotation des moteurs augmentait, le foil se soulevait progressivement jusqu’à sortir de l’eau et entraîner le drone vers l’avant, un comportement non souhaité. Une modification de la répartition des masses — notamment en avançant le boîtier de dérivation — a été testée, mais le foil continuait de décrocher.

26

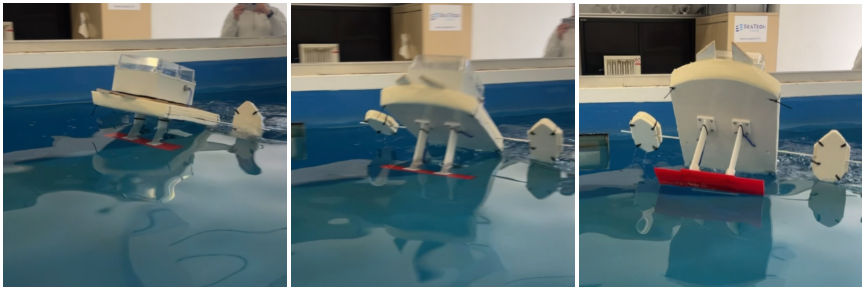
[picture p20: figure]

Figure 5.6 – Décollage et décrochage du foil en T

Face à ces limites, nous avons envisagé l’utilisation d’un foil autoadaptatif. Des travaux théoriques sur ce concept avaient déjà été menés par Anthony GRAILLE et Arthur VARRE, mais aucun essai en bassin n’avait encore été réalisé. Le principe de ce foil repose sur une surface immergée variable : lorsque le foil se lève, la partie immergée diminue, ce qui réduit la portance et stabilise naturellement la hauteur de vol. À vitesse constante, le drone peut ainsi maintenir une altitude stable.
La conception de ce nouveau foil a été réalisée sous SolidWorks. Nous avons conservé le profil hydrodynamique du foil initial, qui avait démontré son efficacité pour assurer le décollage du drone. La courbure définie par Anthony GRAILLE a été reprise, avec des dimensions ajustées afin que le foil reste plus court que les mâts des moteurs, évitant ainsi que ceux-ci ne sortent de l’eau. Le profil est positionné aux extrémités supérieure et inférieure de la courbure, tandis qu’un profil intermédiaire à incidence neutre est placé au creux de la courbure. Les trois sections sont ensuite reliées par un bossage à base lissée suivant la courbure, garantissant la continuité des surfaces internes et externes.

Figure 5.7 – Structure du foil

Pour intégrer ce foil au système existant, deux modèles de fixation ont été développés :

27 l’un horizontal et l’autre vertical.
— Fixation horizontale : positionnée sous le drone, elle constitue une solution simple, robuste et aisément imprimable. Sa localisation sous la ligne de flottaison induit toutefois une perturbation hydrodynamique.
— Fixation verticale : montée latéralement, elle minimise les perturbations du champ d’écoulement autour du foil. Sa géométrie plus complexe rend cependant l’impression 3D plus délicate et nécessite un contrôle accru des tolérances.

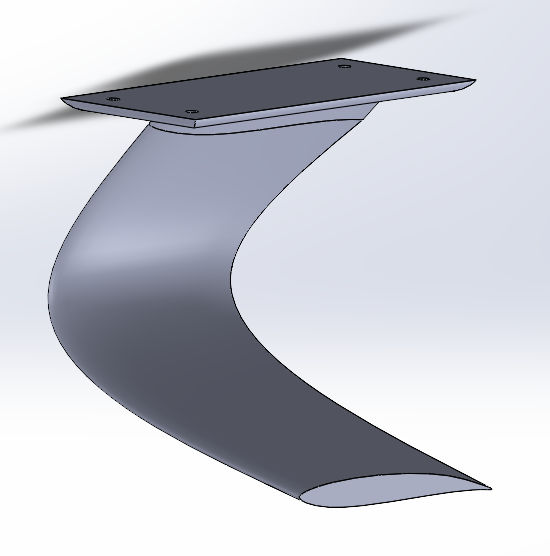
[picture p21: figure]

Figure 5.8 – Foil avec fixation horizontale

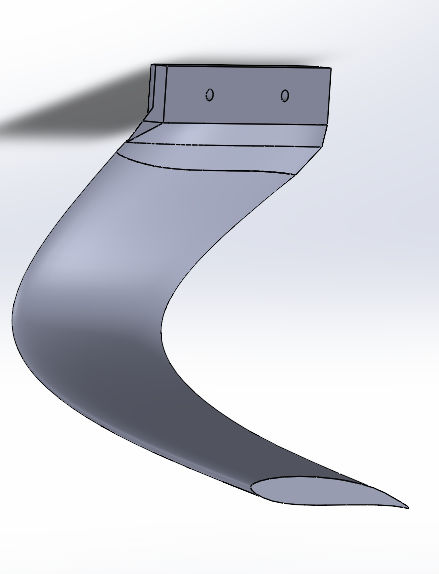
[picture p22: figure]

Figure 5.9 – Foil avec fixation verticale

28

### 5.5 Résultats

L’ensemble des tests a été réalisé sans module gyroscopique, avec un drone qui pesait 4.120 kg.
Pour le foil en T, les premiers essais ont démontré une bonne flottabilité et stabilité latérale. Le foil a tendance à décrocher vers l’avant. Pour résoudre ce problème, nous avons déplacé le centre des masses en modifiant la position de la boîte (posée sur velcro) ainsi que la position de la batterie (élément le plus lourd après les gyroscopes). Ainsi on parvient à faire décoller le drone bien que celui-ci reste sujet à une forte instabilité en tangage, se manifestant par des cabrages fréquents. Une accélération progressive a permis d’atteindre une phase de vol stabilisée, mais la faible longueur du bassin limite la durée de ce comportement.

Pour le foil à moustache l’auto-stabilisation attendue n’est pas nettement constatée. En effet le drone adopte un comportement similaire à celui qui’l avait avec le foil en T. On observe de nouveau un bon décollage mais aussi un cabrage récurrent.
Il s’agit surtout dans les deux cas de réussir à lisser manuellement l’accéleration nette initiale pour lever le drone puis la décélération lente pour le stabiliser. Cela pourra être réalisé grâce au capteur de hauteur.
La meilleure solution est de charger complètement les batteries pour s’assurer d’une puissance maximale des propulseurs nécessaires au décollage, d’autant plus s’il est prévu prochainement d’alourdir le drone avec les modules gyroscopiques.

29

## 6 Axes d’évolution et d’amélioration du projet

### 6.1 Coque

En fonction de la taille et du poids des gyroscopes choisi, il faudra changer la taille de la boîte pour pouvoir les accueillir et leur permettre de s’incliner. ce changement de poids pourra aussi potentiellement induire un changement de taille de planche, plus grande pour assurer la flottabilité.

### 6.2 Commande

l’objectif principal est de réussir à lire correctement les données renvoyées par le capteur de hauteur pour pouvoir maintenir le drone décollé grâce à un algorithme. Il faut pour cela réaliser de nouveaux tests en bassin afin de déterminer une vitesse de croisière de base et une hauteur idéale à viser grâce aux capteurs. L’objectif ensuite est de créer un algorithme qui adapterait la vitesse des moteurs en fonction de la hauteur du drone au dessus de l’eau pour le stabiliser sur son foil.
La structure du code serait en premier de recuperer toutes les données dont nous avons besoin (la hauteur de vol, les données de la télecomandes...) Puis accelérer si on est en dessous de la hauteur souhaitée, décélérer si on est au dessus de la hauteur souhaitée (exemple en annexe)
Pour pouvoir utiliser le moteur destiné à l’inclinaison du module gyroscopique, il faut acheter un ESC brushed qui accepte les batteries 3S, qui peut largement supporter les 5,5 A nécessaires pour le moteur et qui soit compatible avec la Navigator. Une des solutions possibles est le Hobbywing QuicRun 1060 (Brushed).
Au niveau des branchements il faudra achter les connecteurs compatibles avec les câbles des ESC, du recepteur pour pouvoir les connecter à la carte Navigator. Actuellement les connexions sont faites avec les bons embouts de câblage mais il manque les connecteurs JST-GH pour avoir une solution pérenne.
Dans le cas d’un unique gyroscope, une réorientation longitudinale du boîtier électronique étanche aura à être effectuée afin de mettre en adéquation l’axe du module gyroscopique avec le contrôle en tangage du drone. Cette modification structurelle s’accompagnera d’un ajustement précis des perçages et des interfaces de branchement des propulseurs, permettant une intégration plus cohérente au sein de l’architecture en U actuelle tout en préservant l’intégrité de l’étanchéité du système.

30

À terme, le projet prévoit l’évolution du système vers l’intégration de deux gyroscopes afin d’assurer une gestion complète de l’assiette, couvrant simultanément les axes de tangage et de roulis. Cette configuration duale permettra de stabiliser le vol sur foil de manière plus réactive et précise face aux diverses perturbations hydrodynamiques rencontrées lors de la navigation. Pour cela, il faudra adapter la boîte de dérivation à l’architecture à deux gyroscopes, en prenant compte de leur encombrement et de la masse que cela ajouterait.

Par ailleurs, l’optimisation mécanique du moyeu d’accouplement, faisant office de bouchon moteur, nécessite un passage à l’usinage en aluminium en remplacement du prototypage en fabrication additive. Ce choix de matériau est impératif pour absorber les efforts de précession intenses subis par cette pièce critique, garantissant ainsi la rigidité structurelle et la fiabilité de la transmission de puissance au sein du groupe motoréducteur.

Une perspective majeure pour la finalisation du système réside dans l’intégration logicielle et le raccordement électrique du potentiomètre de précision RS PRO 3590, actuellement fixé mécaniquement sur l’architecture. La mise en œuvre de son câblage vers la carte d’acquisition permettra d’exploiter son retour d’état analogique afin de mesurer l’inclinaison du disque d’inertie en temps réel. Cette étape est cruciale pour valider les modèles de simulation, car elle offrira une donnée de feedback indispensable à l’asservissement en boucle fermée. L’acquisition et le traitement de ces données de position angulaire permettront d’affiner la précision du contrôle de l’assiette et d’assurer une stabilisation dynamique optimale du drone sur ses foils lors des futurs essais en bassin.

### 6.3 Foil

Lors des essais, on observe que le foil auto-adaptatif nécessite une vitesse importante pour décoller. Augmenter la surface du foil ou son angle d’incidence permettrait de rendre le décollage plus facile.

### 6.4 Protocole d’essai

Pour comparer les différents comportements du drone il est nécessaires de référencer les modifications apportées qui peuvent être nombreuses : position du centre de masse, nature du foil utilisé, présence ou non du capteur de hauteur, consignes de l’utilisateur envoyées au moteur et puissance de moteur disponible en fonction de la charge de la batterie et du bridage des moteurs. Il est indispensable d’établir un protocole d’essai répertoriant l’intégralité de ces paramètres et leurs états. A.2

31

## 7 Conclusion

Ce projet nous a permis de faire avancer concrètement le drone foileur sur plusieurs fronts à la fois.
Mécaniquement, la structure en U du support gyroscopique remplace avantageusement l’ancienne architecture en colonne : elle est plus rigide, plus compacte, et mieux adaptée aux axes de tangage et de roulis que nous avons ciblé. Le nouveau foil autoadaptatif, conçu sous SolidWorks et validé par impression 3D, répond directement au problème de décrochage observé avec le foil en T ,même si son comportement passif reste à confirmer lors de futurs essais. Côté système embarqué, l’ensemble fonctionne : la Navigator communique avec la télécommande Taranis QX7, les scripts Lua assurent la commande différentielle des moteurs, et le capteur de hauteur est physiquement intégré. Le principal point bloquant reste la lecture correcte de ses données sous BlueOS, ce qui empêche pour l’instant la mise en place de la régulation automatique d’altitude.

Les essais en bassin ont montré que le drone, pesant 4,1 kg sans gyroscope, est capable de décoller de manière répétable. Maintenir une altitude stable reste cependant difficile manuellement, ce qui confirme l’importance de la régulation automatique à venir. L’intégration effective du module gyroscopique dans la boucle de commande constitue la prochaine étape naturelle du projet.
Les perspectives d’évolution pour les promotions suivantes sont clairement établies : finaliser la lecture du capteur ultrasonique, développer l’algorithme de régulation d’altitude, acquérir un ESC brushed compatible 3S pour activer le moteur de précession, et à terme intégrer un second gyroscope pour couvrir simultanément le roulis et le tangage.

32

## A Coder en Lua

A.1 Code moteurs

1 | local STEP = 15 | -- Vitesse de transition ( plus grand =
| plus rapide )
2 | local current_pwm = 1500 -- Valeur de d p a r t au d m a r r a g e du
| script

3
4 | -- ==========================================================
5 | -- FONCTION PRINCIPALE
6 | -- ==========================================================
7 | local function update ()
8 | -- 1. LECTURE DES E N T R E S
9 | local raw_thr | = rc : get_pwm (1)
10 | local raw_str | = rc : get_pwm (4)
11 | local raw_sf | = rc : get_pwm (5)
12 | local raw_spd | = rc : get_pwm (6)
13 | local speed_gyro = rc : get_pwm (8)

14
15 | -- 2. S C U R I T | ( CH5 )
16 | if raw_sf < 1200 then
17 | SRV_Channels : set_output_pwm (94 , 990)
18 | SRV_Channels : set_output_pwm (95 , 990)
19 | -- On force aussi le gyro au repos ou au minimum si
| s c u r i t | active
20 | current_pwm = 1500
21 | SRV_Channels : set_output_pwm (98 , 1500)
22 | return update , 50
23 | end

24
25 | -- 3. LIMITEUR DE VITESSE ( CH6 )
26 | local speed_mult = 1.0
27 | if raw_spd < 1300 then
28 | speed_mult = 0.33
29 | elseif raw_spd < 1700 then
30 | speed_mult = 0.67
31 | else
32 | speed_mult = 1
33 | end

34
35 | -- 4. NORMALISATION ET MIXAGE ( Direction / Gaz )

33

36 | local throttle = math . max (0 , math . min (1 , ( raw_thr - 990) /
| 1010) )
37 | local steering = math . max ( -1 , math . min (1 , ( raw_str - 1500) /
400) )

38
39 | local left_base | = throttle + ( steering * 0.5)
40 | local right_base = throttle - ( steering * 0.5)

41
42 | -- 5. RECONVERSION ET ENVOI MOTEURS
43 | local final_l = math . floor ( math . max (990 , math . min (2000 , 990 + (
| left_base * 1010 * speed_mult )) ))
44 | local final_r = math . floor ( math . max (990 , math . min (2000 , 990 + (
| right_base * 1010 * speed_mult ))) )

45
46 | SRV_Channels : set_output_pwm (94 , final_l )
47 | SRV_Channels : set_output_pwm (95 , final_r )

48
49 | -- 6. GESTION DU GYRO ( LES 3 MODES PROGRESSIFS )
50 | local target_pwm
51 | if speed_gyro < 1300 then
52 | target_pwm = 1500
53 | elseif speed_gyro < 1700 then
54 | target_pwm = 1600
55 | else
56 | target_pwm = 1700
57 | end

58
59 | -- Calcul de la rampe ( Slew Rate )
60 | if current_pwm < target_pwm then
61 | current_pwm = math . min ( current_pwm + STEP , target_pwm )
62 | elseif current_pwm > target_pwm then
63 | current_pwm = math . max ( current_pwm - STEP , target_pwm )
64 | end

65
66 | -- Envoi au canal 98
67 | SRV_Channels : set_output_pwm (98 , math . floor ( current_pwm ))

68
69 | return update , 50 -- Boucle toutes les 50 ms (20 Hz )
70 | end

71
72 | -- Lancement du script
73 | return update ()
Listing A.1 – Script ArduPilot Lua pour controles des moteur

A.2 Code hauteur

1 | -- Script Foil Complet - Correctif Syntaxe
2 | local port = serial : find_serial (0)
3 | local derniere_hauteur_cm = 0

34

4 local dernier_envoi_ms = 0

5
6 | -- Seuils de s c u r i t
7 | local SEUIL_FREINAGE = 45 % distance au dessus de l ’ eau | laquelle
on commence | ralentir
8 | local SEUIL_URGENCE = 55 % distance au dessus de l ’ eau | laquelle
on freine c o m p l t e m e n t pour ne pas sortir les moteurs de l ’ eau

9
10 | function update ()
11 | -- 1. Verification du port
12 | if not port then
13 | gcs : send_text (0 , " Erreur : Port serie non trouve ")
14 | return update , 1000
15 | end

16
17 | -- 2. Lecture du capteur ( Boucle de lecture )
18 | while port : available () >= 4 do
19 | local b = port : read ()
20 | if b == 0 xFF then
21 | local high = port : read ()
22 | local low = port : read ()
23 | local sum = port : read ()

24
25 | local distance_mm = ( high * 256) + low
26 | derniere_hauteur_cm = distance_mm / 10

27
28 | -- Envoi de la donnee au systeme ArduPilot
29 | rangefinder : set_distance (0 , distance_mm / 1000)
30 | end -- FIN du if b == 0 xFF
31 | end -- FIN du while port : available

32
33 | -- 3. Logique d ’ affichage et securite
34 | local temps_actuel = millis ()
35 | if temps_actuel - dernier_envoi_ms > 2000 then
36 | if derniere_hauteur_cm > SEUIL_URGENCE then
37 | gcs : send_text (0 , " URGENCE : " .. derniere_hauteur_cm ..
| " cm ")
38 | else
39 | gcs : send_text (6 , " Foil : " .. derniere_hauteur_cm .. "
| cm ")
40 | end
41 | dernier_envoi_ms = temps_actuel
42 | end

43
44 | return update , 50
45 | end -- FIN de la fonction update

46
47 return update , 1000
Listing A.2 – Script ArduPilot Lua pour capteur de hauteur

35

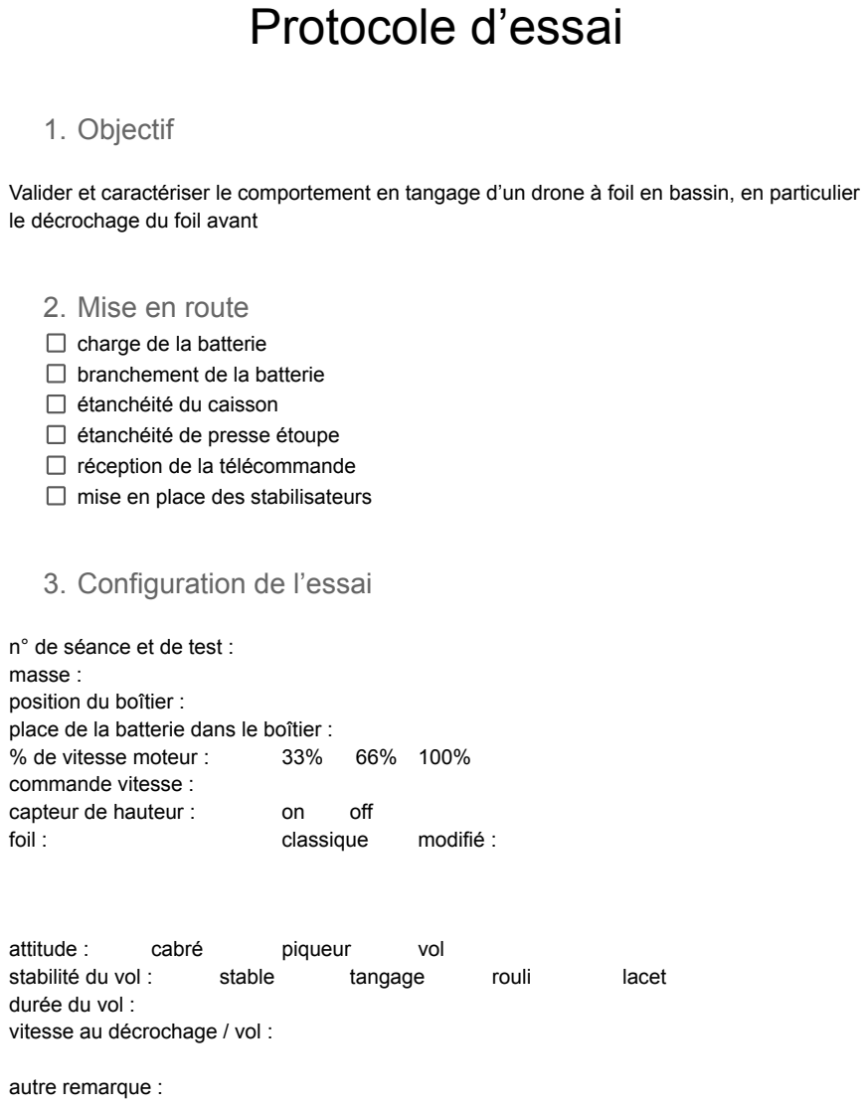
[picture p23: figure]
Protocole d’essai; 1. Objectif; le décrochage du foil avant; 2. Mise en route; charge de la batterie branchement de la batterie étanchéité du caisson étanchéité de presse étoupe réception de la télécommande mise en place des stabilisateurs; 3. Configuration de l’essai; n° de séance et de test : masse : position du boîtier : place de la batterie dans le boîtier :; % de vitesse moteur :; commande vitesse :; capteur de hauteur :; off; foil :; classique; modifié :; attitude :; cabré; piqueur; vol; stabilité du vol :; stable; tangage; rouli; lacet; durée du vol : vitesse au décrochage / vol :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

Valider et caractériser le comportement en tangage d’un drone à foil en bassin, en particulier

36

## B Tutoriel BlueOS

B.1 Première connexion

Pour commencer il faut alimenter la carte (en USB type C ou via une batterie) et brancher la carte a un ordinateur via RJ45

Lors de la 1ère utilisation de blue OS il faut configurer le port ethernet de son PC Adresse IP du PC : 192.168.2.1
Masque sous réseau : 255.255.255.0
Pour cela aller dans les paramètre réseau de l’ordinateur (pour ceux n’ayant pas de port RG45 natif assurez-vous d’être bien connecté physiquement à la carte avant)
Ensuite aller dans un navigateur à l’adresse http ://192.168.2.2 (ou juste 192.168.2.2) Je conseille de passer la carte en mode Pirate (Le symbole de tête de mort) et de connecter la carte à un réseau wi-fi.

B.2 Connexions suivantes

Les connexions suivantes seront normalement plus simples et plus rapides. Si le PC à déjà été connecté à la carte il suffit d’alimenter la carte, se connecter en RG45 et aller à l’adresse http ://192.168.2.2

37

B.3 Presentation de l’OS

Figure B.1 – Blue OS

Sur la gauche nous avons les différentes fonctions. Les fonctions les plus intéressantes sont Autopilot Parameters (qui va nous permettre de changer les paramètres de notre robot), File Browser (permet d’accéder aux fichiers de la carte, pour coder par exemple), MAV-Link Inspector (permet notamment de voir ce qui arrive sur le RC Chanel) et Vehicule Setup (permet de parametrer certain paramètres du robot de manière plus intuitive que dans autopilote parameters)

En haut a gauche nous avons les données de base, si le coeur "bat" cela signifie que la carte est bien connectée au PC. On voit aussi le mode pirate, la connexion à un réseau wi-fi...
On peut aussi installer le logiciel QGroudControl qui permet de modifier les paramètres et de contrôler le drone (une sorte de logiciel complémentaire à BlueOS). Cela nécessite néanmoins d’être connecté de la même manière.

B.4 Protocole RC

Le protocole RC nous permet de communiquer avec la carte via une RadioTelecomande. Pour cela commencer par connecter physiquement le récepteur de la télecomande a la carte, et connecter le récepteur à la télécommande (petite led verte sur le récepteur pour assurer la connection)
Nous avons passé le firmware du robot en Vehicle type : Ground Rover
En effet en mode Sub la connection RC est imposssible.
Ensuite dans Autopilot Parameters modifier les paramètres suivants :

38

-SERIAL1_PROTOCOL en RCIN
-ARMING_CHECK à None. (Cela permet de contourner le protocole de preArmement qui est bien plus compliqué en Rover)
Normalement on peut voire le signal dans MAVLink Inspector.

B.5 Coder en lua

pour pouvoir implémenter ses propres codes il est nécessaire de suivre la démarche suivante : Aller dans Autopilot Parameters et mettre SCR_ENABLE sur 1.
Ensuite dans File Browser, entrer dans home -> configs -> ardupilot-manager -> firmware, puis finalement dans le dossier Scripts (s’il n’existe pas le créer)
Ensuite il est possible de créer des fichier en lua (bien mettre .lua)

Pour récuperer le signal du RC : rc : get_pwm(1)
Pour envoyer le signal sur une sortie moteur : SRV _Channels : set_output_pwm(94, V aleur)

B.6 Piloter un moteur

Aller dans Vehicule Setup, puis aller dans PWM Output.

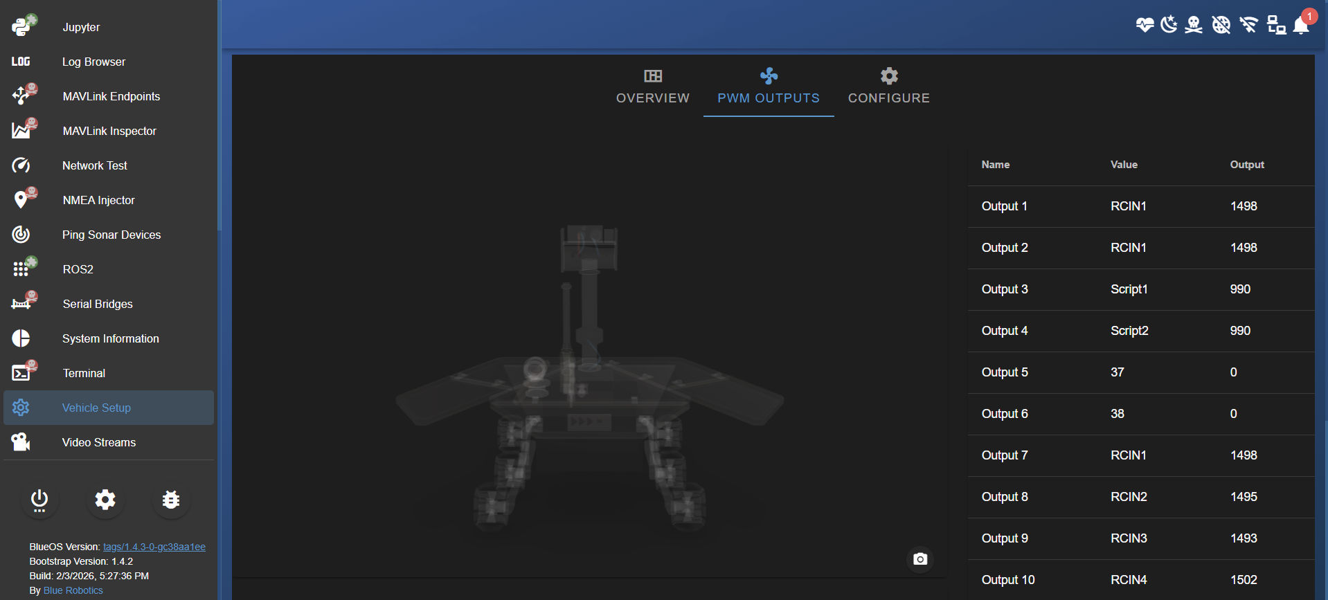
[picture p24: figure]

Figure B.2 – Vehicule Setup -> PWM Output

Ensuite il faut choisir le mode que vous voulez sur la sortie que vous avez choisi. Pour avoir les sorties souhaitées en lua choisir le mode Script1 (ou scriptX le numero que vous recherchez) si ce mode n’apparaît pas aller dans Autopilot Parameters et choisir SERVO1_FUNCTION Custom 94

39

94 correspond a Script1, 95 Script2...

40

## C Scripts MATLAB

C.1 Script de balayage du centre de gravité

Ce script permet de faire varier la position du bloc gyroscopique dans Simulink et de tracer les courbes de réponse en tangage et roulis pour identifier le point d’équilibre passif.

1 | % D f i n i t i o n du profil NACA
2 | c = 0.15;
3 | t = 0.12;
4 | x = linspace (0 , c , 100) ’;
5 | yt = 5* t *c *(0.2969* sqrt (x /c) - 0.1260*( x/c ) - 0.3516*( x/ c) .^2 +
| 0.2843*( x/ c) .^3 - 0.1015*( x/c ) .^4) ;
6 | points = [ flipud (x ) , flipud ( yt ) ; x (2: end) , - yt (2: end) ];

7
8 | % Section Aillette
9 | c_aillette = 0.1;
10 | c_t = 0.08;
11 | x = linspace (0 , c_aillette , 50) ’;
12 | c_yt = 5* c_t * c_aillette *(0.2969* sqrt (x / c_aillette ) - 0.1260*( x /
| c_aillette ) - 0.3516*( x/ c_aillette ) .^2 + 0.2843*( x / c_aillette )
| .^3 - 0.1015*( x / c_aillette ) .^4) ;
13 | c_points = [ flipud (x ) , flipud ( c_yt ); x (2: end) , - c_yt (2: end) ];

14
15 | % Script de positionnement optimal
16 | model = ’ Simul2Gyro_2_naca_bloque ’;
17 | load_system ( model );
18 | ecart_fixe = 0.06; % Distance entre les deux gyros du bloc

19
20 | positions_groupe = linspace ( -0.15 , 0.15 , 8) ;
21 | figure (’ Name ’, ’ Recherche de la position d ’’ quilibre | du Foil ’);
22 | colors = jet( length ( positions_groupe )) ;

23
24 | for i = 1: length ( positions_groupe )
25 | pos_centre = positions_groupe (i) ;

26
27 | valeur_bloc1 = sprintf (’ [% f 0 0.03] ’, pos_centre + ecart_fixe );
28 | valeur_bloc2 = sprintf (’ [% f 0 0.03] ’, pos_centre - ecart_fixe );

29
30 | set_param ([ model ’/ R7 ’] , ’ TranslationCartesianOffset ’,
| valeur_bloc1 );
31 | set_param ([ model ’/ R10 ’], ’ TranslationCartesianOffset ’,

41

valeur_bloc2 );

32
33 | simOut = sim ( model , ’ ReturnWorkspaceOutputs ’, ’on ’, ’
| FastRestart ’, ’ off ’) ;
34 | t = simOut . tout ;

35
36 | try
37 | % R c u p r a t i o n XS ( Roulis ) au lieu de Ys ( Tangage )
38 | angle_roulis = simOut . logsout .get(’ XS ’). Values . Data ;
39 | hold on ;
40 | plot (t , angle_roulis , ’ Color ’, colors (i ,:) , ’ LineWidth ’,
| 1.5 , ...
41 | ’ DisplayName ’, sprintf (’ Position : %.2 f m ’, pos_centre
| )) ;
42 | catch
43 | disp (’ Signal XS ( Roulis ) introuvable . ’) ;
44 | end
45 | end

46
47 | % Mise en page
48 | grid on ;
49 | legend (’ Location ’, ’ best ’);
50 | title (’ Inclinaison l a t r a l e ( Roulis ) selon la position des
| gyroscopes ’) ;
51 | xlabel (’ Temps (s) ’) ;
52 | ylabel (’ Angle de Roulis ( deg ) ’) ;

53
54 | % T r a a g e de la ligne noire | paisse | sur le z r o
55 | yline (0 , ’k - ’, ’ LineWidth ’, 2, ’ DisplayName ’, ’ Objectif : 0 | ( Plat
| parfait ) ’);
Listing C.1 – Balayage automatique de position et analyse de stabilite

C.2 Architecture du modèle Simulink

La figure suivante présente l’organisation des blocs Simscape utilisée pour simuler le comportement dynamique du drone et l’influence de la position du gyroscope sur les axes de roulis et de tangage.

42

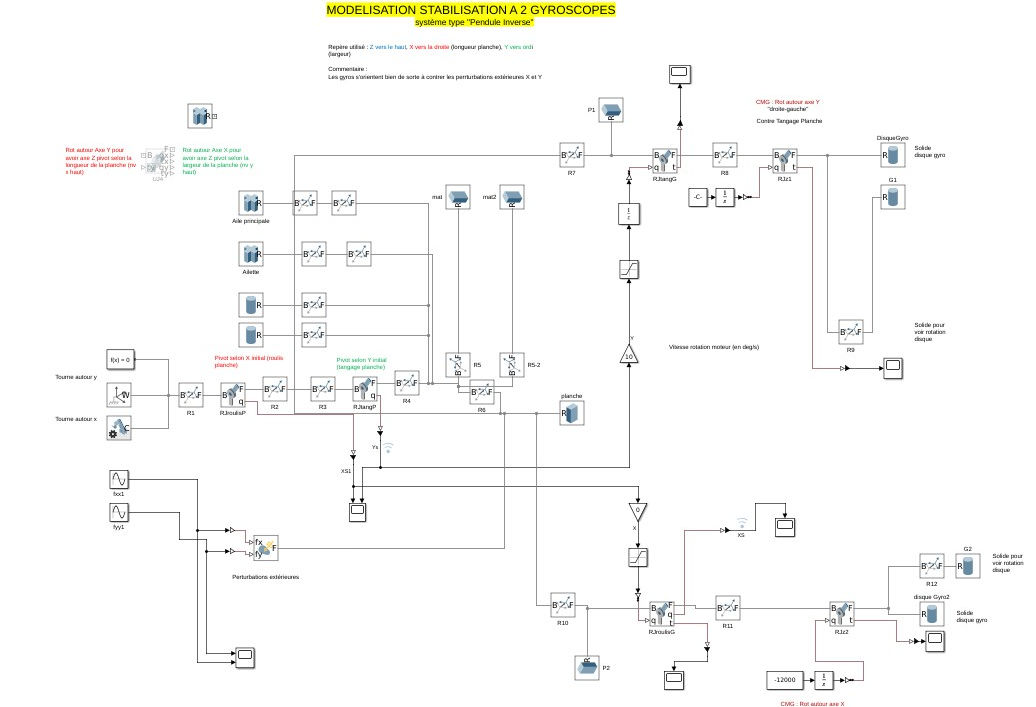
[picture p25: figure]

Figure C.1 – Schéma-bloc du modèle Simulink (Drone à foil et stabilisation gyroscopique)

43

## D Mises en plan

44

7 6

1 812

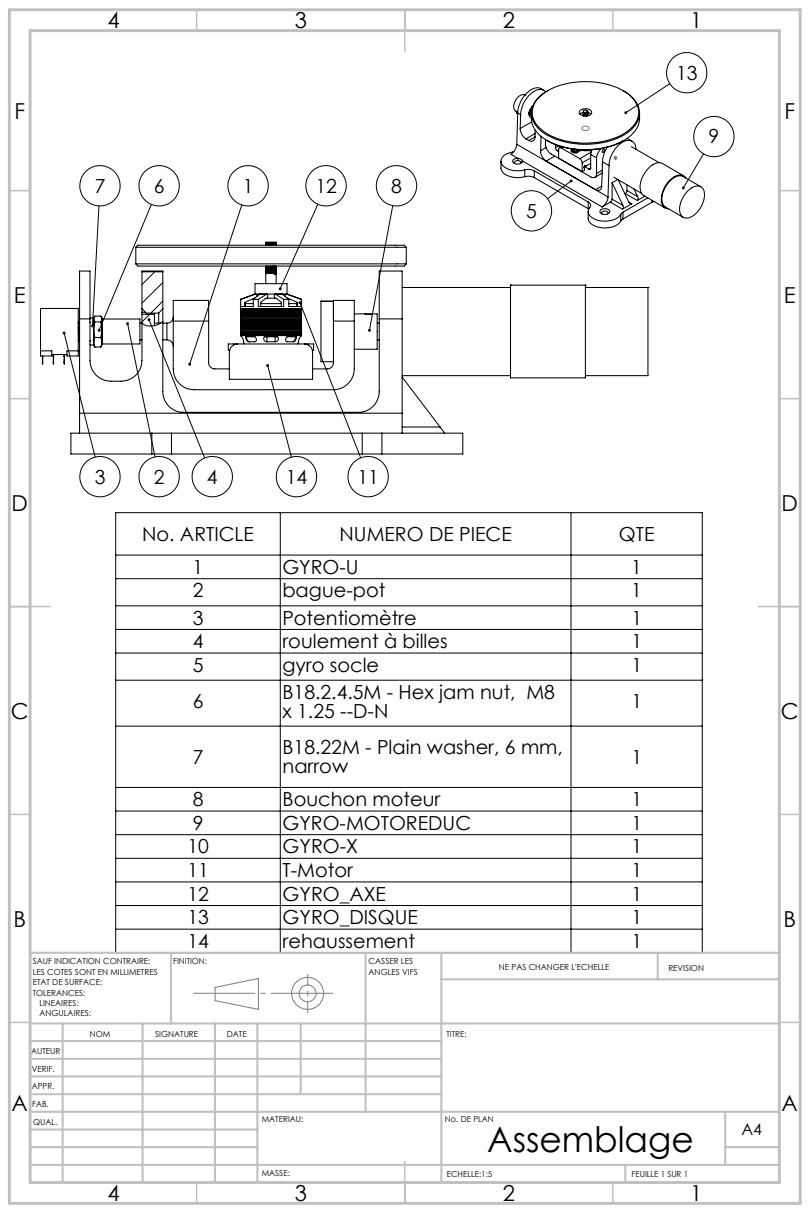
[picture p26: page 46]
GYRO_DISQUE; FAB.; QUAL.; MATERIAU:; ECHELLE:1:5; FEUILLE 1 SUR 1; MASSE:

No. ARTICLE | NUMERO DE PIECE | QTE
1 | GYRO-U | 1
2 | bague-pot | 1
3 | Potentiomètre | 1
4 | roulement à billes | 1
5 | gyro socle | 1

B18.2.4.5M - Hex jam nut, M8

7 | B18.22M - Plain washer, 6 mm, narrow | 1

8 | Bouchon moteur | 1
9 | GYRO-MOTOREDUC | 1
10 | GYRO-X | 1
11 | T-Motor | 1
12 | GYRO_AXE | 1
14 | rehaussement | 1

SAUF INDICATION CONTRAIRE: LES COTES SONT EN MILLIMETRES ETAT DE SURFACE: TOLERANCES: LINEAIRES: ANGULAIRES: | FINITION: | CASSER LES ANGLES VIFS | NE PAS CHANGER L'ECHELLE | REVISION

NOM | SIGNATURE | DATE | TITRE:

AUTEUR
VERIF.
APPR.

No. DE PLAN
Assemblage

11,00

10,00 5,00

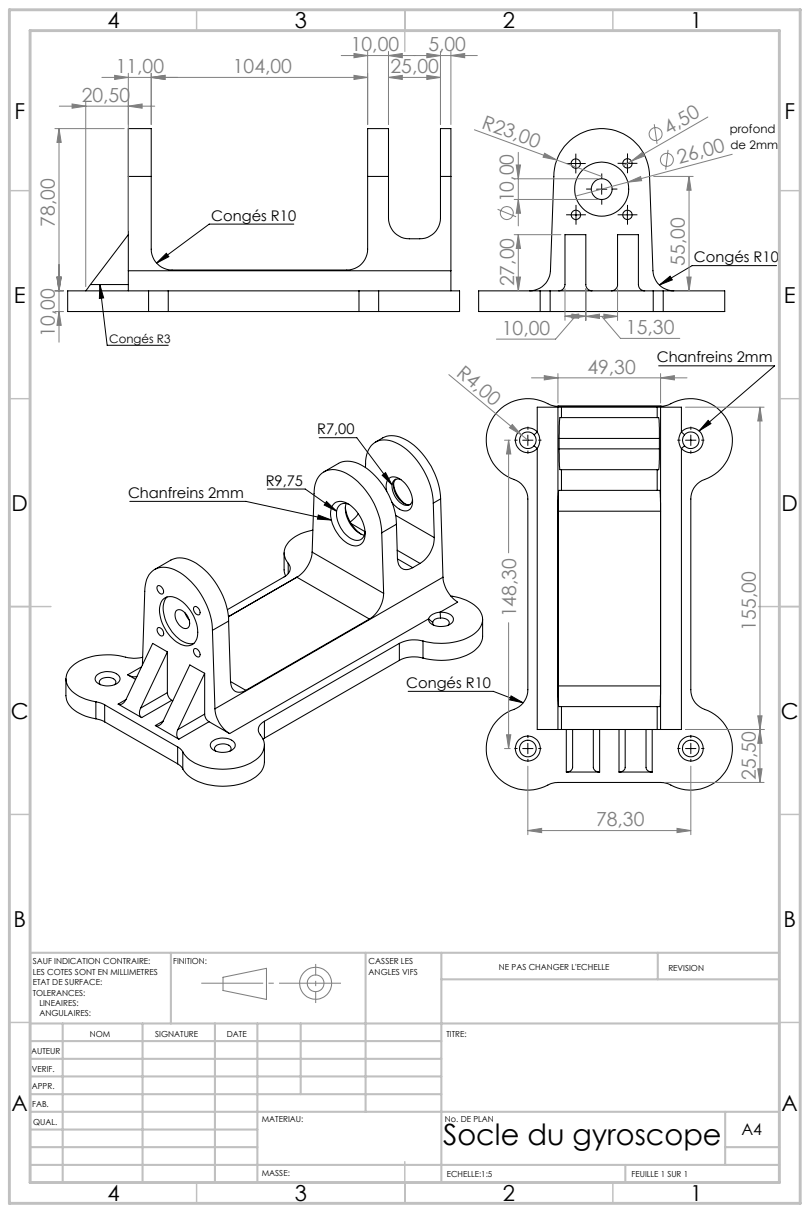
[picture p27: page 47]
Congés R10; profond de 2mm; Congés R3; 49,30 Chanfreins 2mm; Chanfreins 2mm; FAB.; QUAL.; FINITION:; CASSER LES; ANGLES VIFS; MATERIAU:; NE PAS CHANGER L'ECHELLE; REVISION; ECHELLE:1:5; FEUILLE 1 SUR 1; MASSE:

SAUF INDICATION CONTRAIRE:
LES COTES SONT EN MILLIMETRES
ETAT DE SURFACE:
TOLERANCES:
LINEAIRES:
ANGULAIRES:

NOM | SIGNATURE | DATE | TITRE:

AUTEUR
VERIF.
APPR.

No. DE PLAN
Socle du gyroscope

42,00

21,00

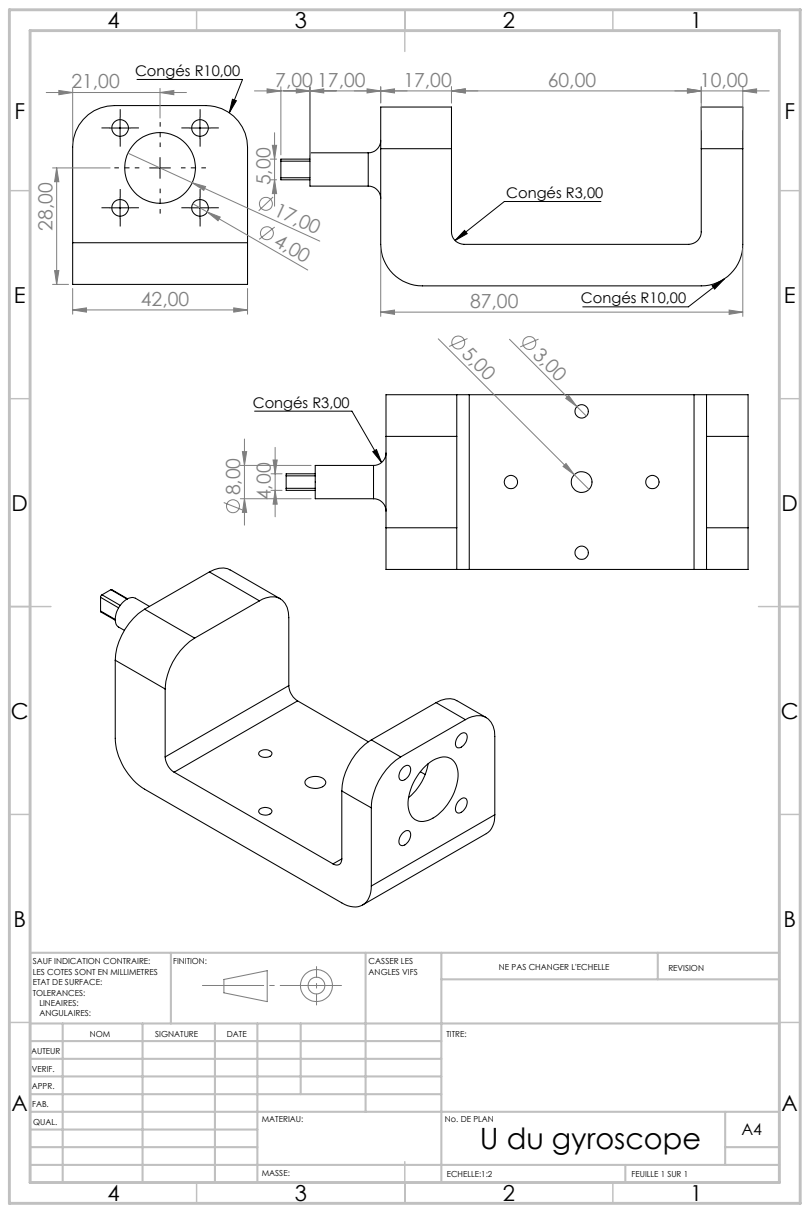
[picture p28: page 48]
Congés R10,00; Congés R3,00; FAB.; QUAL.; FINITION:; CASSER LES; ANGLES VIFS; MATERIAU:; NE PAS CHANGER L'ECHELLE; REVISION; ECHELLE:1:2; FEUILLE 1 SUR 1; MASSE:

SAUF INDICATION CONTRAIRE:
LES COTES SONT EN MILLIMETRES
ETAT DE SURFACE:
TOLERANCES:
LINEAIRES:
ANGULAIRES:

NOM | SIGNATURE | DATE | TITRE:

AUTEUR
VERIF.
APPR.

No. DE PLAN
U du gyroscope

9,00

E E

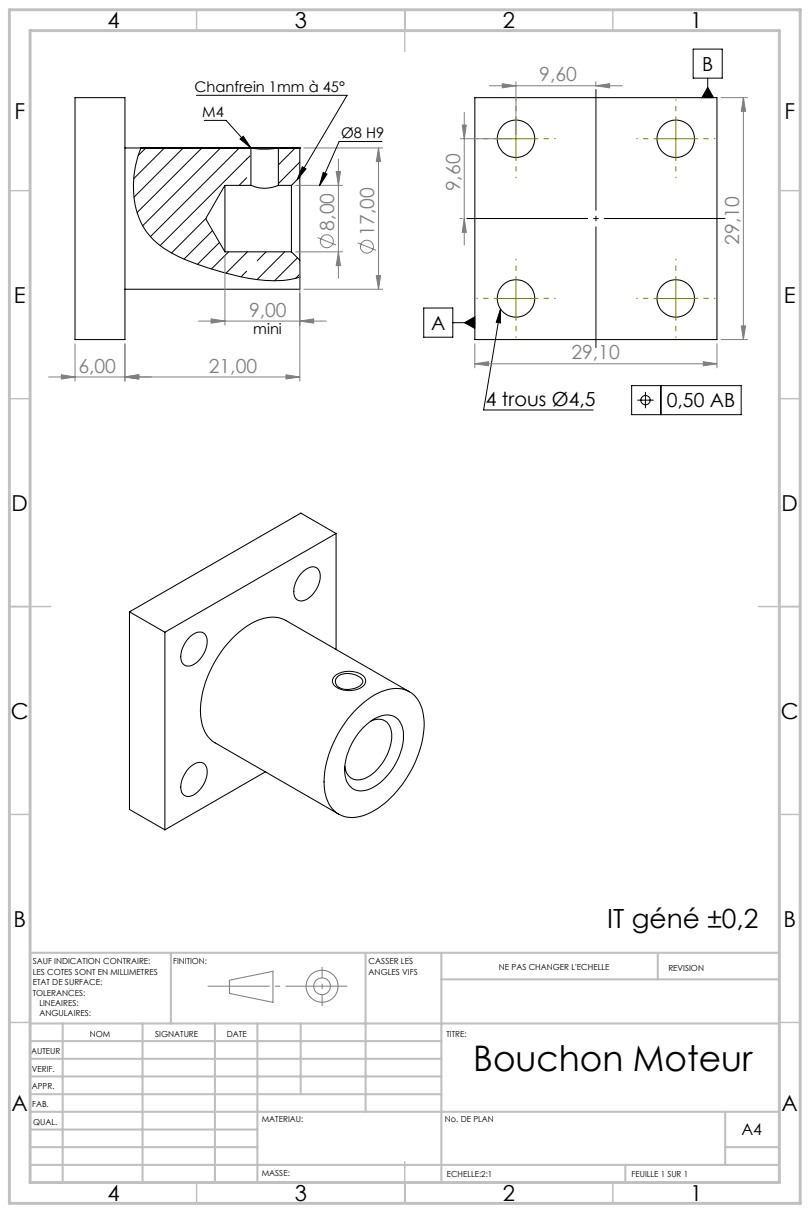
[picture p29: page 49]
Chanfrein 1mm à 45°; 4 trous Ø4,5; IT géné ±0,2; mini; FAB.; QUAL.; FINITION:; CASSER LES; ANGLES VIFS; MATERIAU:; NE PAS CHANGER L'ECHELLE; REVISION; ECHELLE:2:1; FEUILLE 1 SUR 1; MASSE:

SAUF INDICATION CONTRAIRE:
LES COTES SONT EN MILLIMETRES
ETAT DE SURFACE:
TOLERANCES:
LINEAIRES:
ANGULAIRES:

NOM | SIGNATURE | DATE | TITRE: Bouchon Moteur

AUTEUR
VERIF.
APPR.

No. DE PLAN

17,00

51,00

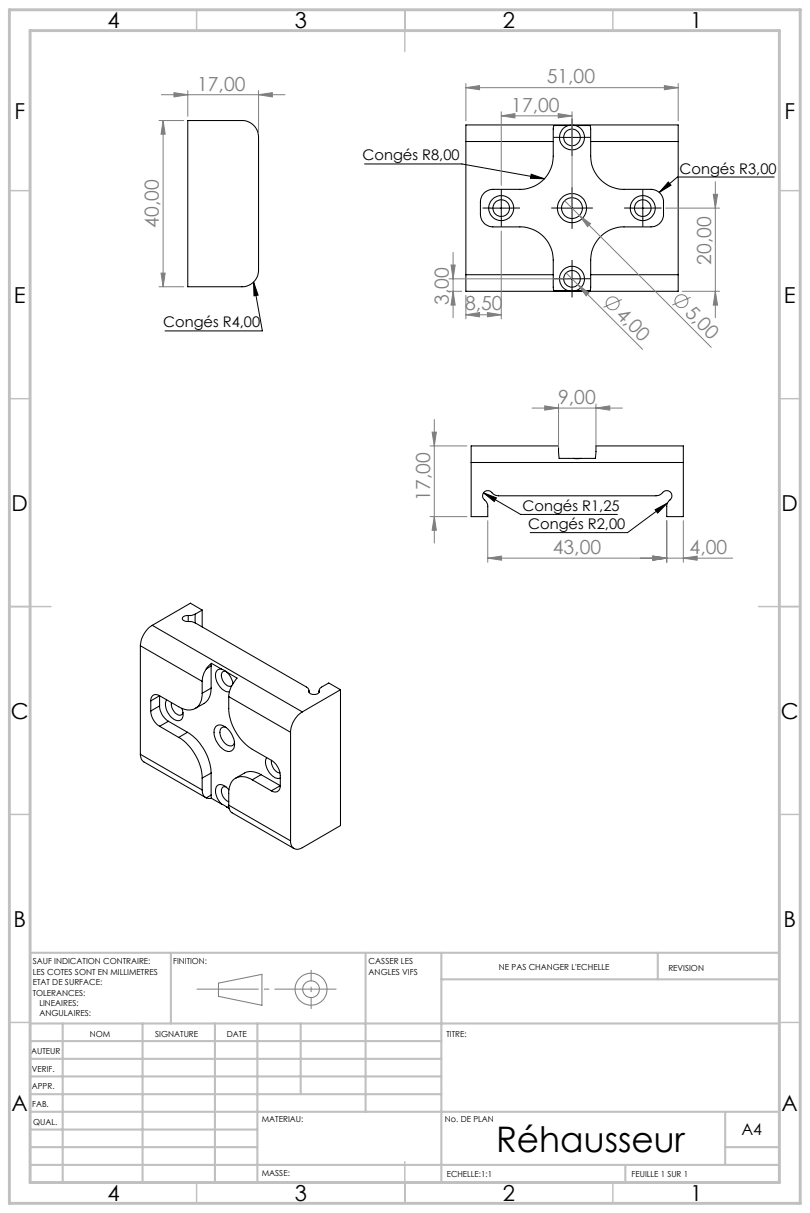
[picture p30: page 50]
Congés R4,00; Congés R8,00; Congés R3,00; Congés R1,25 Congés R2,00; FAB.; QUAL.; FINITION:; CASSER LES; ANGLES VIFS; MATERIAU:; NE PAS CHANGER L'ECHELLE; REVISION; ECHELLE:1:1; FEUILLE 1 SUR 1; MASSE:

SAUF INDICATION CONTRAIRE:
LES COTES SONT EN MILLIMETRES
ETAT DE SURFACE:
TOLERANCES:
LINEAIRES:
ANGULAIRES:

NOM | SIGNATURE | DATE | TITRE:

AUTEUR
VERIF.
APPR.

No. DE PLAN
Réhausseur

AA

E E

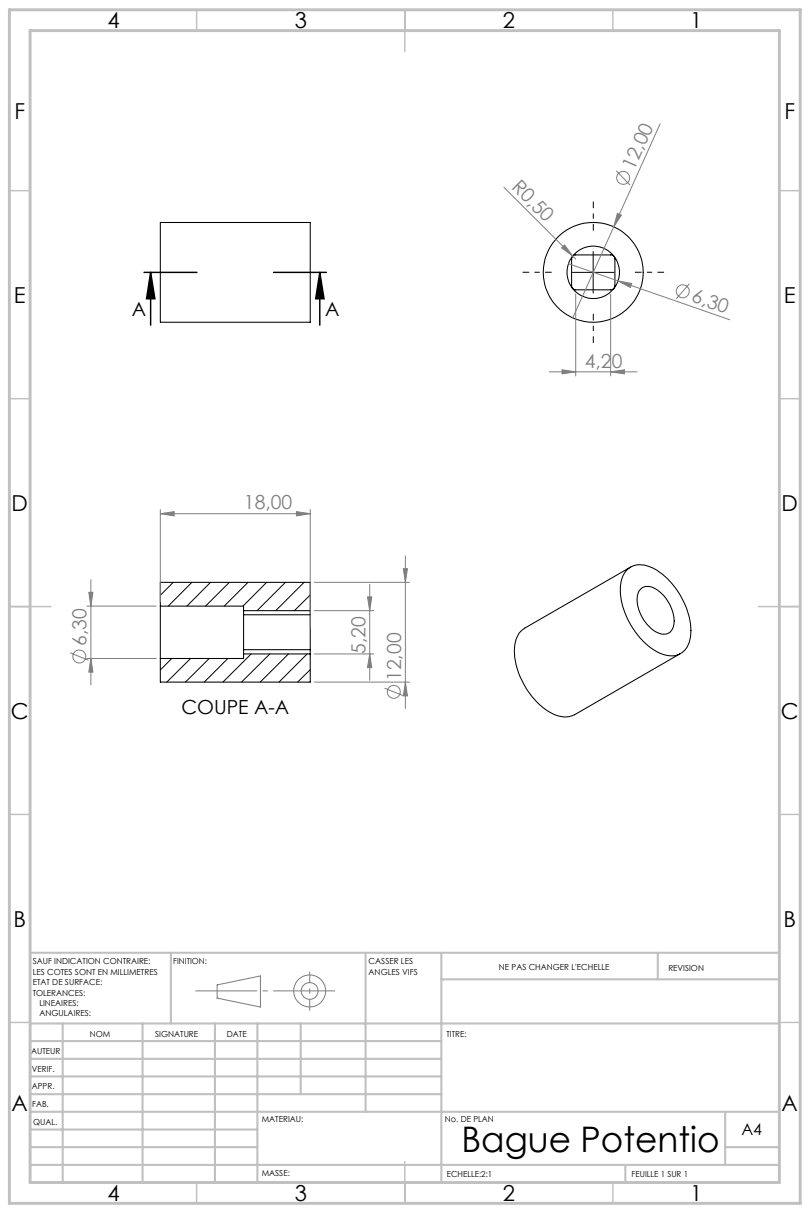
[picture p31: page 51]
COUPE A-A; FAB.; QUAL.; FINITION:; CASSER LES; ANGLES VIFS; MATERIAU:; NE PAS CHANGER L'ECHELLE; REVISION; ECHELLE:2:1; FEUILLE 1 SUR 1; MASSE:

SAUF INDICATION CONTRAIRE:
LES COTES SONT EN MILLIMETRES
ETAT DE SURFACE:
TOLERANCES:
LINEAIRES:
ANGULAIRES:

NOM | SIGNATURE | DATE | TITRE:

AUTEUR
VERIF.
APPR.

No. DE PLAN
Bague Potentio

## E Protocole d’assemblage

51

52

53

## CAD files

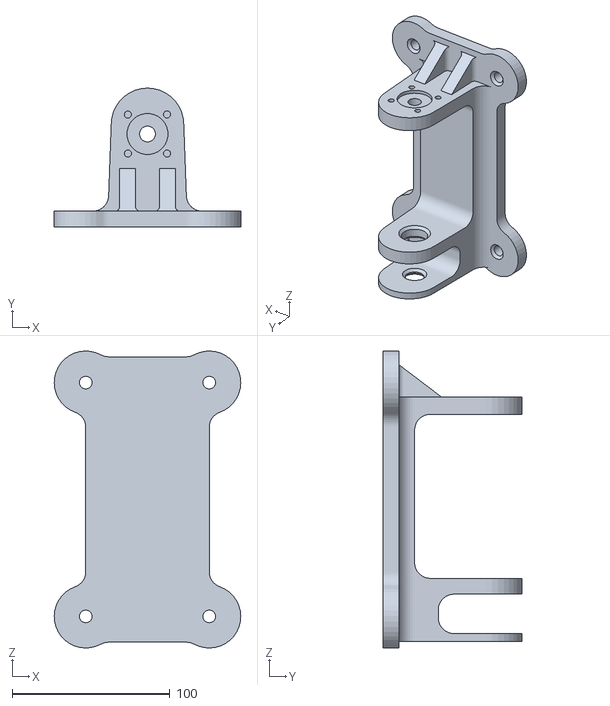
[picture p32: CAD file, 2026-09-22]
cad/gyro socle.STL
118.3 x 88.0 x 188.3

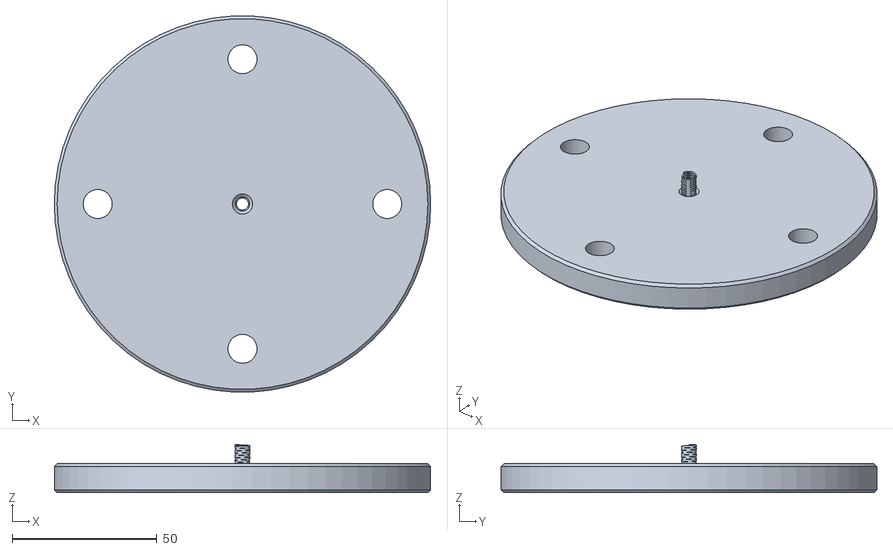
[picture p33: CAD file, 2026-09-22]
cad/GYRO_DISQUE.STL
130.0 x 129.8 x 16.7

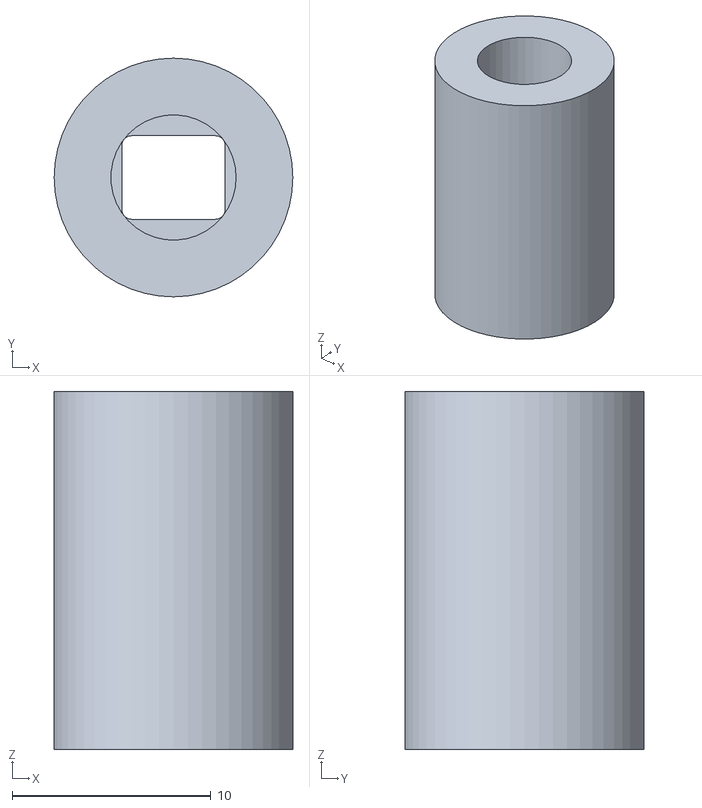
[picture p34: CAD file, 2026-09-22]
cad/bague-pot.STL
12.0 x 12.0 x 18.0

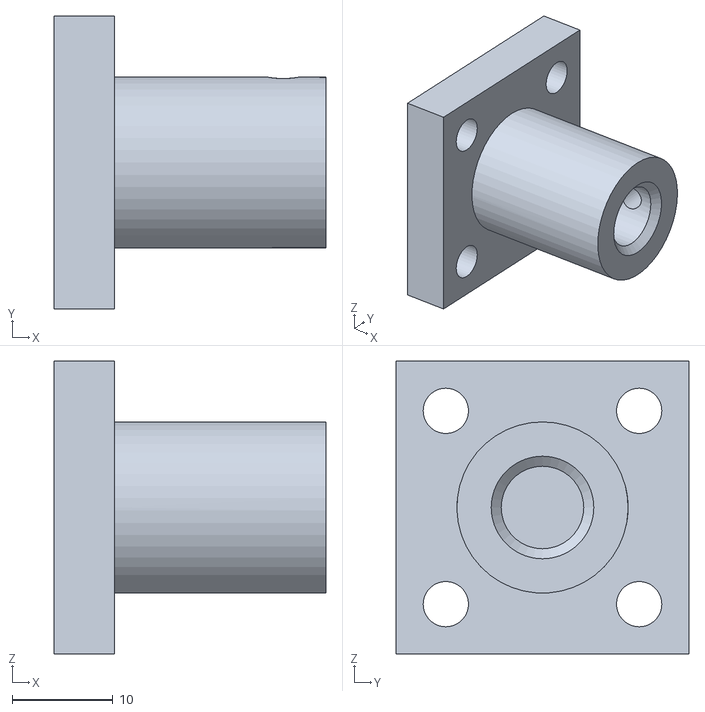
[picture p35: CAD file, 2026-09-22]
cad/Bouchon moteur.STL
27.0 x 29.1 x 29.1

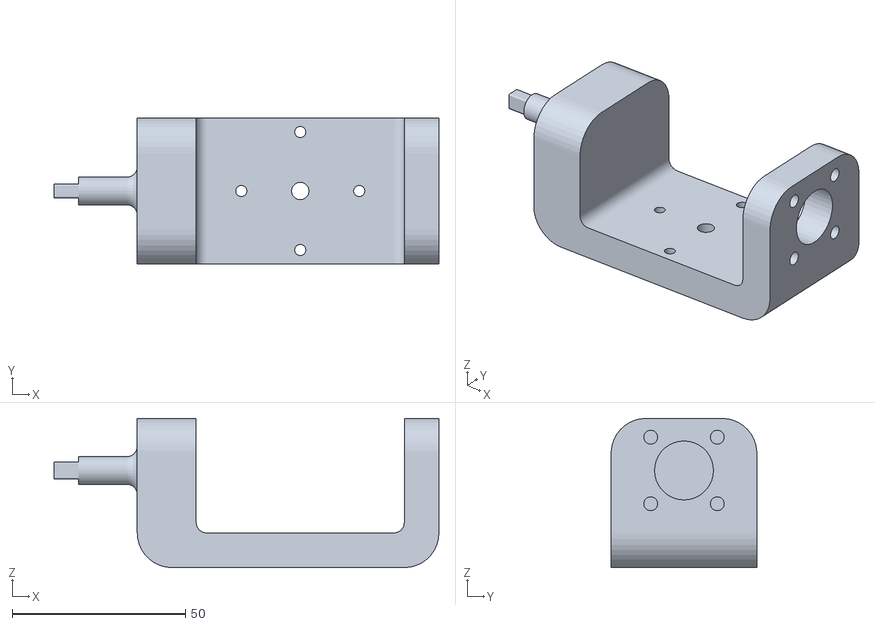
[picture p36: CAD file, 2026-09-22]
cad/GYRO-U.STL
111.0 x 42.0 x 43.0

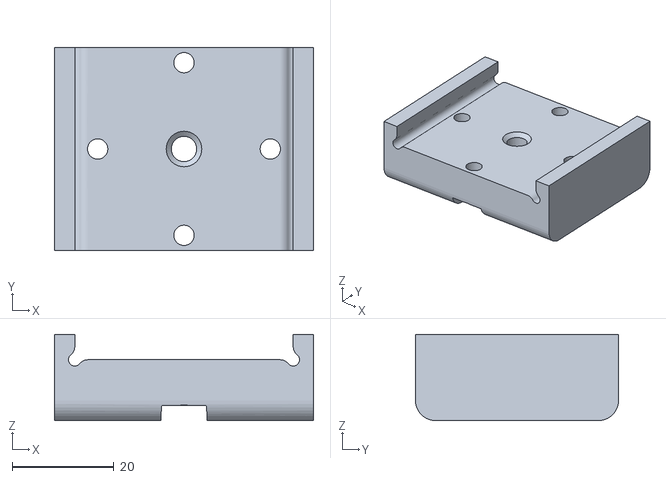
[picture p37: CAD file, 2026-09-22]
cad/rehaussement.STL
51.0 x 40.0 x 17.0

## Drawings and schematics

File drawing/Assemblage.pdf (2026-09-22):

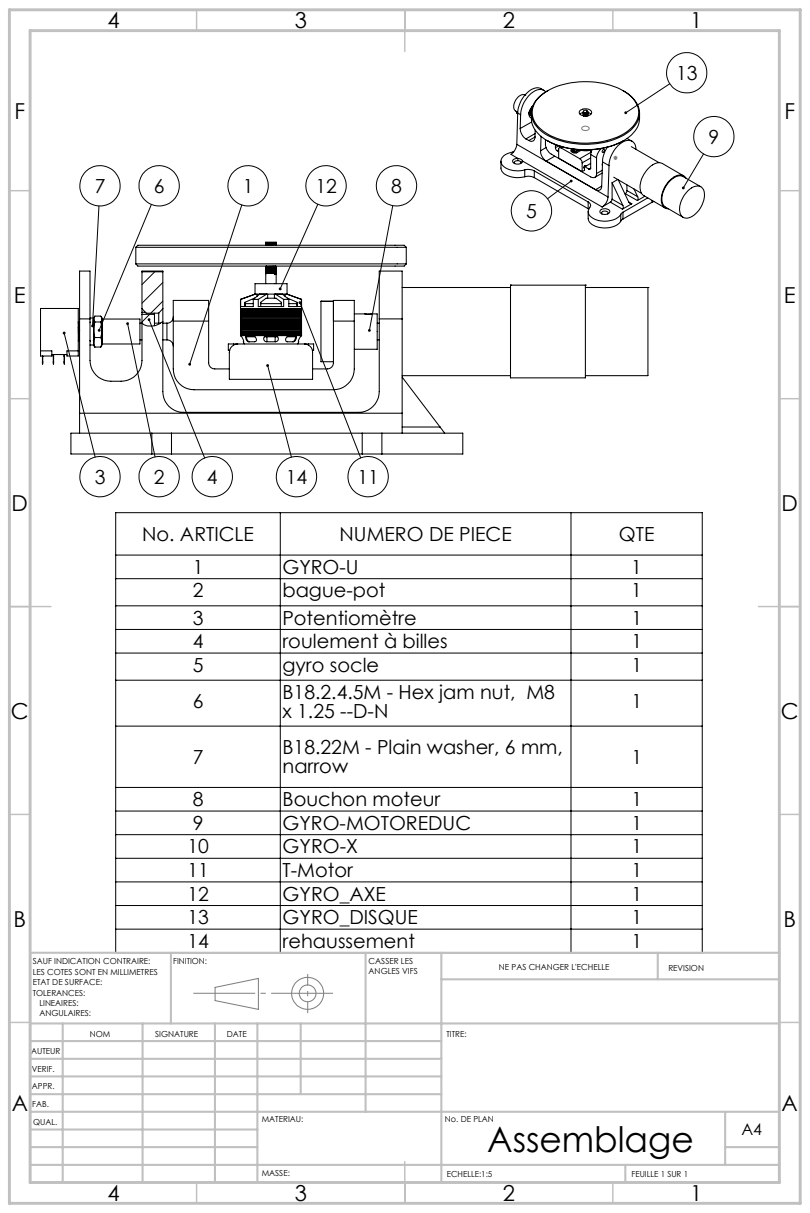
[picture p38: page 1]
ECHELLE:1:5; FEUILLE 1 SUR 1

No. ARTICLE | NUMERO DE PIECE | QTE
1 | GYRO-U | 1
2 | bague-pot | 1
3 | Potentiomètre | 1
4 | roulement à billes | 1
5 | gyro socle | 1
6 | B18.2.4.5M - Hex jam nut, M8 x 1.25 --D-N | 1

7 | B18.22M - Plain washer, 6 mm, narrow | 1

8 | Bouchon moteur | 1
9 | GYRO-MOTOREDUC | 1
10 | GYRO-X | 1
11 | T-Motor | 1
12 | GYRO_AXE | 1
13 | GYRO_DISQUE | 1
14 | rehaussement | 1

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

NOM | SIGNATURE | DATE | | | | TITRE:

AUTEUR
VERIF.
APPR.
FAB.
QUAL. | | | | MATERIAU: | No. DE PLAN Assemblage | A4

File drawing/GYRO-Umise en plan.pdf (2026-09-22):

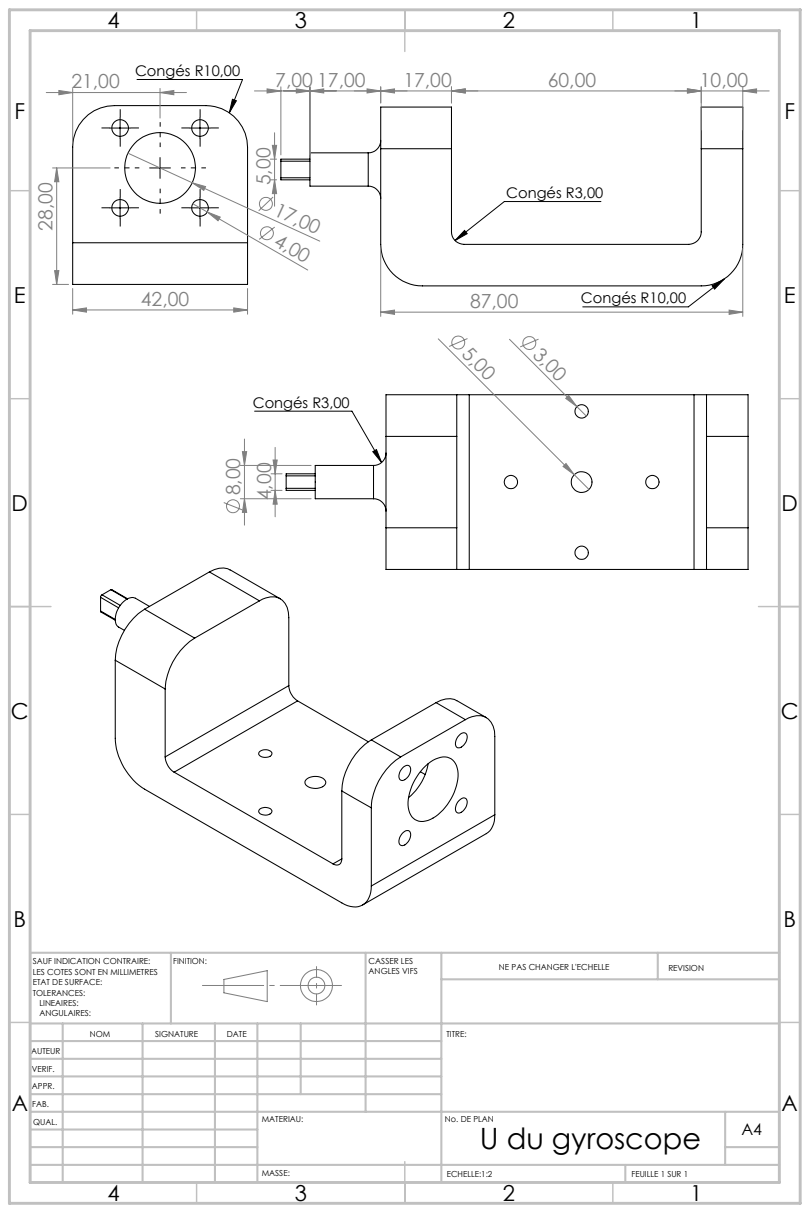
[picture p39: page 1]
Congés R10,00; Congés R3,00; FINITION:; CASSER LES; ANGLES VIFS; NE PAS CHANGER L'ECHELLE; REVISION; ECHELLE:1:2; FEUILLE 1 SUR 1

SAUF INDICATION CONTRAIRE:
LES COTES SONT EN MILLIMETRES
ETAT DE SURFACE:
TOLERANCES:
LINEAIRES:
ANGULAIRES:

NOM | SIGNATURE | DATE | | | | TITRE:

AUTEUR
VERIF.
APPR.
FAB.
QUAL. | | | | MATERIAU: | No. DE PLAN U du gyroscope | A4

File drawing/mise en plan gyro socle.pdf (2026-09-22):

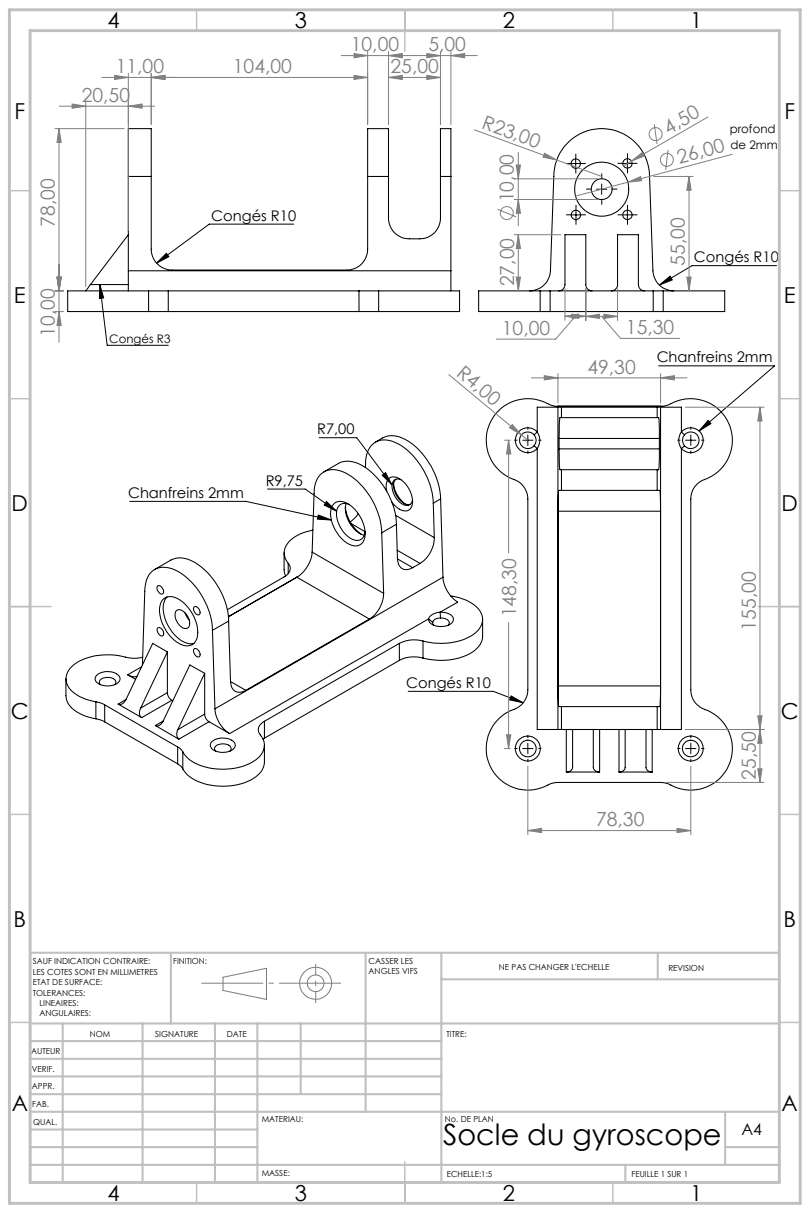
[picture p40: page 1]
Congés R10; Congés R3; 49,30 Chanfreins 2mm; Chanfreins 2mm; FINITION:; CASSER LES; ANGLES VIFS; NE PAS CHANGER L'ECHELLE; REVISION; ECHELLE:1:5; FEUILLE 1 SUR 1

SAUF INDICATION CONTRAIRE:
LES COTES SONT EN MILLIMETRES
ETAT DE SURFACE:
TOLERANCES:
LINEAIRES:
ANGULAIRES:

NOM | SIGNATURE | DATE | | | | TITRE:

AUTEUR
VERIF.
APPR.
FAB.
QUAL. | | | | MATERIAU: | No. DE PLAN Socle du gyroscope | A4
